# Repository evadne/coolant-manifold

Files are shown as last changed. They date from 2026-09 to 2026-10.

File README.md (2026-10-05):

# Rack coolant manifold and Supernova mount

A ten-pair coolant manifold and a radiator mounting plate for 19-inch open racks. The manifold routes parallel coolant flow through two long galleries in a single machined POM body. A flat stainless faceplate mounts it to the rack; fittings seal directly against raised POM bosses. A separate 10U plate mounts an Alphacool Supernova radiator and four Noctua NF-A20 fans.

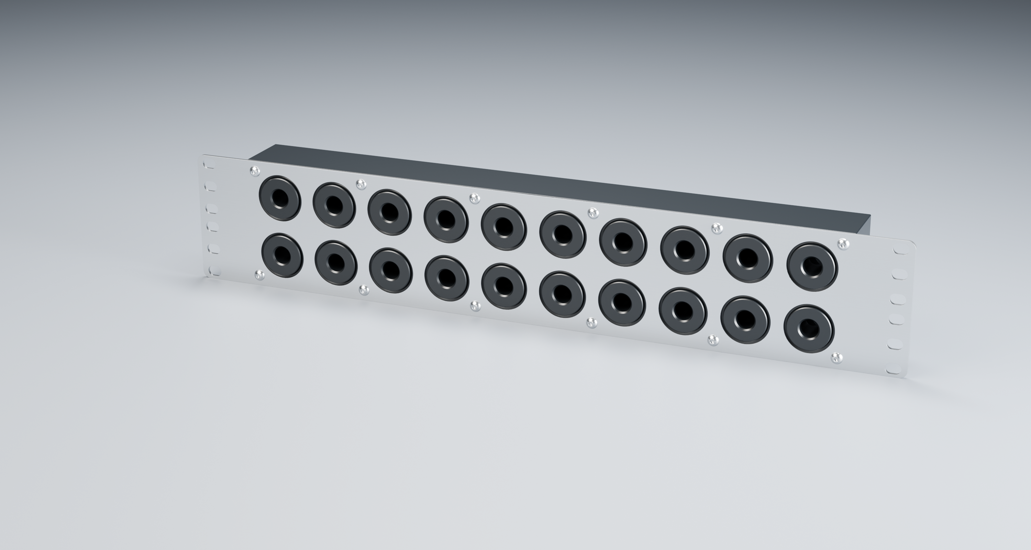
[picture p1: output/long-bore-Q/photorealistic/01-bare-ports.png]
Angled studio render of the assembled manifold with bare ports


*Current Q manifold assembly. Rendered materials are illustrative; the steel fabrication specification is raw sheet finish.*

**To manufacture the same three parts, start with [Order these parts from JLC](docs/order-from-jlc.md).** It lists the exact ZIPs and supplier settings. No CAD software or regeneration is needed to use the existing fabrication pack.

## Canonical fabrication files

Current set: **Q-M04 POM body + Q-M03 faceplate + R7-M01 radiator plate**. These are the revisions used for the delivered first articles. Geometry revisions Q/R7 and manufacturing revisions Q-M04/Q-M03/R7-M01 are distinct; an older Q-M01 body is not the current Q-M04 body.

| Part | Main dimensions in mm | Download for manufacture | Technical drawing |
|---|---|---|---|
| Q-M04 manifold body | 410 × 87 × 40 slab; 3 mm bosses | [Body ZIP](output/submission/current-three-parts/RM10-Q-M04-BODY.zip) | [Body PDF](output/pdf/RM10-Q-M04-BODY.pdf) |
| Q-M03 manifold faceplate | 482.6 × 87 × 2; 2U allocation | [Faceplate ZIP](output/submission/current-three-parts/RM10-Q-M03-FACEPLATE.zip) | [Faceplate PDF](output/pdf/RM10-Q-M03-FACEPLATE.pdf) |
| R7-M01 radiator plate | 482.6 × 444.5 × 2; 10U | [Radiator ZIP](output/submission/current-three-parts/SN1260-R7-M01-PLATE.zip) | [Radiator PDF](output/pdf/SN1260-R7-M01-PLATE.pdf) |

Each ZIP contains one part's STEP and fabrication PDF; steel ZIPs also contain a DXF. **STEP holes are tapping pilots: the accompanying PDF defines the finished G1/4 and M4 threads.** Assembly models, STL meshes and renders are not substitutes for the fabrication bundles.

For tools and AI readers, [cad/current-release.json](cad/current-release.json) lists the canonical revisions, paths and SHA-256 hashes. [The output guide](output/README.md) explains historical and shared dependencies. Earlier versions remain in their original locations.

## What the manifold provides

- Twenty front G1/4 female ports: ten pairs at 40 × 40 mm centres. Four side and four rear ports provide alternative infrastructure connections.
- Two continuous common galleries, with no internal grouping. Feeding from the sides or rear leaves all ten front pairs available for loads.
- One unfilled black POM-C or POM-H body. There is no sealed cover joint; fitted plugs and couplings provide their own face seals.
- Twenty raised bosses with chamfered lips and rounded roots, projecting nominally 1 mm beyond the 2 mm steel plate.
- Twelve plain M4 faceplate fixing holes and optional rack slots. Assembly uses M4×10 button-head screws; no countersinks.

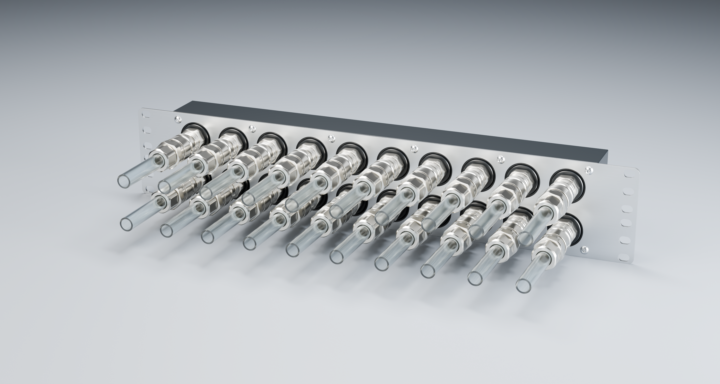
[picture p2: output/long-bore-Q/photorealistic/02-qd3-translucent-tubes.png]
Current manifold with Koolance QD3 pairs and translucent tubing


*Studio presentation uses official, unscaled Koolance QD3-MTG4 and QD3-FT10X13 reference models. Coupled registration is described in the [fitting notes](docs/koolance-qd3-studio-integration.md).*

## Hardware received

The manifold and faceplate have been manufactured. On 5 October 2026, the operator verified their dimensions, the POM M4 holes and G1/4 ports, smooth QD3 engagement and mounting without perceptible plate flex. The radiator plate is delivered but operator-unverified, pending a spare Supernova. No leak-test result has yet been reported.

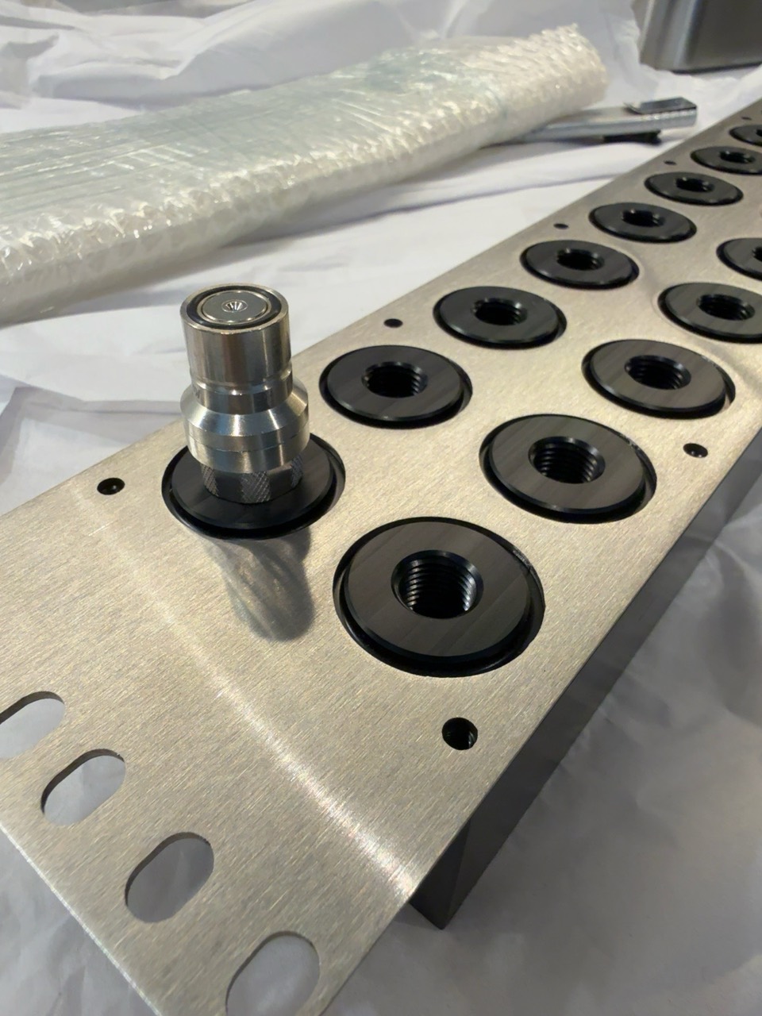
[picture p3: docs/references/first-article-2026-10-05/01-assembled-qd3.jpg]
Received manifold and faceplate with one fitted QD3


*Operator photograph of the first article, during fit checking.*

The first parts were made by **JLCCNC**. Observations about POM holding marks and slight steel-edge sharpness concern that delivered batch; they are documented in the [JLCCNC first-article report](docs/jlc-first-article.md), alongside the accepted fit and remaining finish question. They are not a general judgement of raw stainless steel or other manufacturers.

## Radiator plate and rack context

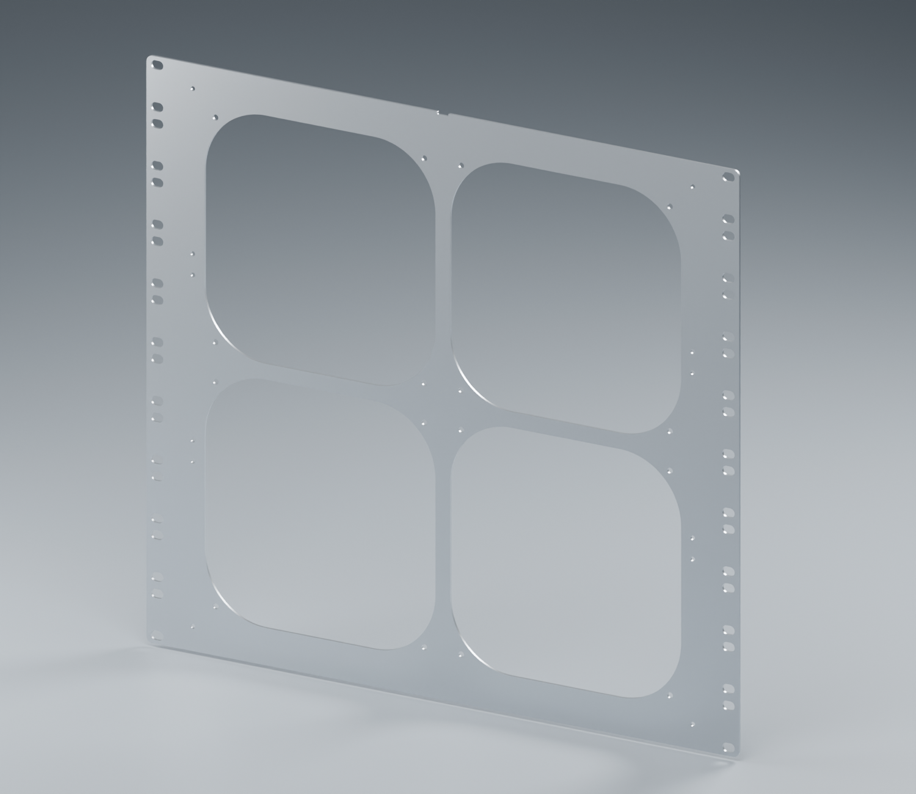
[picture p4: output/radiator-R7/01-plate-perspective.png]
Angled render of the R7 radiator plate


The flat plate has four fan apertures, plain fan fixing holes for screws and nuts, radiator-frame fixing holes, optional rack slots and a rounded cable notch. The illustrated 25U layout places the radiator below the host, the manifold above it and eight water-cooled GPUs higher in the rack. [Assembly guidance](docs/radiator-rack-plate.md) and the [rack scene](docs/context-25U.md) explain the arrangement.

These are prototype designs with physical manifold fit verification, not qualified pressure, transport or long-term creep ratings. Side-elbow clearance to rack hardware remains a separate actual-hardware check. Detailed assumptions and limits are in [manufacturing status](docs/manufacturing.md) and the linked engineering studies.

## Explore or reproduce the project

| Goal | Start here |
|---|---|
| Order the same parts | [JLC repeat-order guide](docs/order-from-jlc.md) |
| Understand dimensions and materials | [Three-part recap](docs/three-part-recap.md) |
| Assemble the manifold | [Assembly guide](docs/assembly-Q.md) |
| Find engineering evidence and history | [Documentation index](docs/README.md) |
| Rebuild CAD, PDFs or Blender scenes | [Rebuild guide](docs/rebuild.md) |
| Read the project retrospective | [Astra's commentary](docs/astra-commentary.md) |
| Make and order a new revision | [Contributor workflow](docs/new-revision.md) |
| Set up macOS authoring tools | [Environment setup](docs/rebuild.md#environment) |
| Contribute changes | [Working rules](AGENTS.md) |

The repository retains substantial CAD, Blender and analysis history. The [publication review](docs/publication-review.md) records repository size, retained supplier records, third-party assets and portability limits. Original project material is licensed under **[CERN-OHL-W-2.0](LICENSE)**; see [licensing and provenance](LICENSING.md) for scope and third-party notices. No blanket reuse grant is implied for manufacturer reference models.

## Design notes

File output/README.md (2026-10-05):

# Output directory guide

Current custom parts: Q-M04 manifold body, Q-M03 faceplate and R7/R7-M01 radiator; both steel plates have four R5 outside corners and ±0.10 cut tolerances. These are the delivered first-article revisions. Start with [the repeat-order guide](../docs/order-from-jlc.md) or [machine-readable selection](../cad/current-release.json).

| Location | Purpose |
|---|---|
| `submission/releases/<name>/` | Independently reviewed quotation packs from `scripts/release.py`; these do not automatically change the canonical delivered selection |
| `submission/current-three-parts/` | Current three-part ZIP index and final consistency manifest |
| `submission/Q-M04/`, `submission/Q-M03/` | Body/faceplate supplier STEP/PDF ZIPs; DXF for steel; checks and remarks |
| `submission/R7-M01/` | Radiator STEP/PDF/DXF ZIP; checks and remarks |
| `manufacturing/Q-M04/`, `manufacturing/Q-M03/`, `manufacturing/R7-M01/` | Derived single-part solids and verified feature schedules |
| `pdf/RM10-Q-M04-BODY.pdf`, `pdf/RM10-Q-M03-FACEPLATE.pdf`, `pdf/SN1260-R7-M01-PLATE.pdf` | Current technical fabrication drawings |
| `assembly/Q/` | Separate reference assembly and selected M4×10 screw; not supplier part uploads |
| `long-bore-Q/cad/` | Original Q-M01 body and baseline geometry/checks; original faceplate/assembly retained as source history. Current plate is manufacturing/Q-M03; current assembly is assembly/Q |
| `long-bore-Q/product-views/` | Current twelve review angles and unmarked/transparent Blender scenes |
| `long-bore-Q/photorealistic/` | Four refreshed studio images, bare/connected Blender scenes |
| `long-bore-P/koolance-fit/` | Shared retained official fitting meshes and provenance |
| `radiator-R7/` | Current radiator CAD, checks and seven refreshed plate/populated assembly/notch/R5 views |
| `context-25U/` | Current Q/R7 StarTech composite, nine views and fit/tubing checks |
| `analysis/Q-retention.json`, `analysis/Q-torque.json` | Explicit preliminary assumptions and numerical sensitivity; not qualified ratings |

Earlier P/O, Q-M01 and R6 manufacturer/review files are historical; do not submit them as the current Q-M04/Q-M03/R7-M01 set. Older `long-bore-*`, `radiator-R1` throughR6, generic24U scenes and unversioned G outputs retain their original history. The R4 FEA remains baseline evidence, not a new R7/Q solver result. [Project guide](../README.md) · [manufacturing](../docs/manufacturing.md) · [assembly](../docs/assembly-Q.md).

## Authority and dependencies

Only the three ZIPs selected by `cad/current-release.json` are canonical fabrication uploads. The current index contains byte-identical copies of the revision-specific archives. PDFs plus STEP/DXF define fabrication; STL and Blender files are display/assembly aids. The original files are retained in place rather than renamed, because historical scripts and current reference scenes still depend on some of them.

A directory labelled `long-bore-Q` is not enough to choose a supplier file: its `cad/` subdirectory retains baseline Q-M01 solids, while current presentation scripts load the finished Q-M04/Q-M03 parts explicitly. `long-bore-P/koolance-fit/` is a shared current reference dependency despite its older revision name. The [revision register](../docs/iterations.md) describes the progression.

No Git LFS migration or historical asset removal has been performed. Large scenes and solver outputs are intentionally retained. Use [the publication review](../docs/publication-review.md) for size/provenance decisions, not a renderer's defaults.

Historical verification records can contain status text from the release date (for example “held” or “submitted”). Preserve that dated meaning when maintaining metadata; field names, source paths and checksums use the current format, with earlier records retained in Git. The canonical manifest selects the parts; [manufacturing status](../docs/manufacturing.md) describes their current physical disposition.

Renderer inputs are retained beside the owning revision: `meshes/` contains tessellations and `render-scene.json` contains placement parameters. The unversioned G inputs live directly under `output/`; its alternative mounting uses `backplate/`. O-M02 presentation meshes live under `manufacturing/O-M02/meshes/`. Q's gallery meshes are diagnostic void volumes; current part surfaces still come from Q-M04/Q-M03.

Structural studies retain compressed `.inp.gz` solver decks, `.dat.gz` results and `.json.gz` node/load metadata together under `radiator-FEA/`, `radiator-expanded-load/`, `radiator-R2/analysis/` and `radiator-R4/analysis/`. Review scripts read these directly. `context-24U/history/`, `context-25U/history/` and `analysis/historical-body-depth-assessment.json` hold earlier exploratory evidence, not current acceptance results.

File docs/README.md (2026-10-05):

# Documentation guide

For another order, use [Order the current parts from JLC](order-from-jlc.md). For current file selection, use [the canonical manifest](../cad/current-release.json) and [fabrication downloads](../output/submission/current-three-parts/README.md). Historical documents retain the context of their original dates; they do not select today's files.

| Subject | Documents |
|---|---|
| Design and interfaces | [Three-part recap](three-part-recap.md), [design](design.md), [Q rear ports](revision-Q-rear-ports.md) |
| Delivered parts and supplier experience | [Manufacturing status](manufacturing.md), [JLCCNC first article](jlc-first-article.md), [order chronology](jlc-order-2026-09-16.md) |
| Manufacture again | [JLC guide](order-from-jlc.md), [body revision](jlc-submission-Q-M04.md), [faceplate revision](jlc-submission-Q-M03.md), [radiator revision](jlc-submission-R7-M01.md) |
| Assembly | [Manifold](assembly-Q.md), [radiator](radiator-rack-plate.md), [fan splitter](radiator-x-splitter-fit.md) |
| Engineering evidence | [Machining route](Q-M04-machining-route.md), [M4 sizing](Q-retention-sizing.md), [torque/creep](Q-torque-and-creep.md), [radiator loads](radiator-load-assessment.md) |
| Coolant assumptions | [POM compatibility](pom-coolant-assessment.md), [Blitz overrun targets](blitz-overrun-qualification.md), [pump pressure](d5-pressure.md) |
| Product presentation | [Views](product-views.md), [Koolance references](koolance-qd3-studio-integration.md), [25U rack](context-25U.md) |
| Rack model details | [PVC equilibrium](pvc-routing-physics.md), [GPU geometry](gpu-5090fe-context.md) |
| New designs | [Create, check and package a revision](new-revision.md) |
| Reproduction | [Rebuild guide](rebuild.md), [output map](../output/README.md) |
| History and reflection | [Revision register](iterations.md), [archive](archive/README.md), [Astra's commentary](astra-commentary.md) |
| Publication | [Review](publication-review.md), [licensing/provenance](../LICENSING.md) |

`AGENTS.md` contains working rules. Rationale belongs in the engineering documents; dated events belong in the order/revision records; supplier-specific findings belong in the JLCCNC report. Numerical and simulated evidence is not silently upgraded to first-article test evidence.

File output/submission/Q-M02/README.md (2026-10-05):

# Q-M02 manifold faceplate submission guide

Issued 16 September 2026. **RM10-Q-M02-FACEPLATE** replaces the Q-M01 faceplate specification only. The accepted Q geometry is unchanged; the POM body remains **RM10-Q-M01-BODY**, with its existing threads, positions and finishes.

Use `output/submission/Q-M02/RM10-Q-M02-FACEPLATE.zip` as one sheet-metal part. It contains matching-name STEP, DXF and two-sheet A3 PDF. The STEP/DXF are byte-identical to the submitted Q-M01 geometry, renamed for this manufacturing issue.

- Material: 304 / EN 1.4301 stainless, 482.6 ×87 ×2 mm, raw sheet finish on both broad faces; no brushing, polishing, coating or markings.
- All non-reference cut dimensions, including hole diameters, slot sizes, profiles and all X/Z coordinates: **±0.10 mm**. Thickness: 2.00 ±0.10 mm.
- W01–W20: Ø32.00 ±0.10 mm windows. H01–H12: Ø4.50 ±0.10 mm plain through holes. R01–R12: 10.00 ±0.10 ×7.00 ±0.10 mm slots; end radius half finished width.
- Free-state flatness: **0.30 mm maximum**, unchanged and separate from dimensional tolerances.
- Standard grinding and deburring on both faces; no specified chamfer or face-edge round size. Complete burr removal is not guaranteed, consistent with the operator-accepted JLC faceplate limitation.
- No tapped holes, countersinks, bends or welds. Manufacturing instructions only; assembly remains in the separate Q assembly guide.

The twelve hole positions and all nominal diameters remain unchanged. The earlier proposed Ø4.5 minimum-hole condition is not retained: the new specification allows Ø4.40–4.60 mm. The [fit assessment](../../../docs/Q-faceplate-as-drawn-capability.md) and [operator acceptance](jlc-feedback-2026-09-16.md#operator-acceptance) are engineering records outside the fabrication ZIP.

**Held for later submission if a repeat order is needed**, by operator decision on 16 September 2026. This package records the accepted dimensional tolerances. Do not replace the current order’s files. The existing order **SMS2609163000694-6347288A** proceeds under the operator’s emailed acceptance; it is a historical reference, not an order for this new issue. No upload of this issue has occurred. Original Q-M01 submitted archives remain intact; see [quotation history](../../../docs/jlc-quotation-2026-09-15.md).

Rebuild: `python3 scripts/prepare_Q_faceplate_manufacturing_revision.py`, then `python3 scripts/draw_Q_production.py --faceplate-manufacturing-revision Q-M02 --faceplate-only`. Render and inspect both sheets, then run `python3 scripts/package_Q_faceplate_manufacturing_revision.py`. Use a Python runtime with ReportLab/pypdf for the final two commands.

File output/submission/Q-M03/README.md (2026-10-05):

# Q-M03 manifold faceplate submission guide

Issued 16 September 2026. **RM10-Q-M03-FACEPLATE** supersedes Q-M02 with four R5 external outline corners; every opening and fixing position is retained; the current companion POM body is **RM10-Q-M04-BODY**, which adds C0.5 slab-edge chamfers while retaining all threads and mating positions.

Use `output/submission/Q-M03/RM10-Q-M03-FACEPLATE.zip` as one sheet-metal part. It contains matching-name STEP, DXF and two-sheet A3 PDF. The STEP/DXF model four R5.00 ±0.10 mm external outline corners. Compared with the submitted square-corner faceplate, only 42.920 mm³ is removed; no material is added. Nominal mass is 0.394607 kg. The minimum opening-to-outer-profile clearance remains 1.90 mm.

- Material: 304 / EN 1.4301 stainless, 482.6 ×87 ×2 mm, raw sheet finish on both broad faces; no brushing, polishing, coating or markings.
- All non-reference cut dimensions, including hole diameters, slot sizes, profiles and all X/Z coordinates: **±0.10 mm**. Thickness: 2.00 ±0.10 mm.
- W01–W20: Ø32.00 ±0.10 mm windows. H01–H12: Ø4.50 ±0.10 mm plain through holes. R01–R12: 10.00 ±0.10 ×7.00 ±0.10 mm slots; end radius half finished width.
- Free-state flatness: **0.30 mm maximum**, unchanged and separate from dimensional tolerances.
- Standard grinding and deburring on both faces; no specified chamfer or face-edge round size. Complete burr removal is not guaranteed, consistent with the operator-accepted JLC faceplate limitation.
- No tapped holes, countersinks, bends or welds. Manufacturing instructions only; assembly remains in the separate Q assembly guide.

The twelve hole positions and all nominal diameters remain unchanged. The earlier proposed Ø4.5 minimum-hole condition is not retained: the new specification allows Ø4.40–4.60 mm. The [fit assessment](../../../docs/Q-faceplate-as-drawn-capability.md) and [operator acceptance](../../../docs/jlc-feedback-2026-09-16.md#operator-acceptance) are engineering records outside the fabrication ZIP.

**Held for later submission if a repeat order is needed**, by operator decision on 16 September 2026. This package records the accepted dimensional tolerances. Do not replace the current order’s files. The existing order **SMS2609163000694-6347288A** proceeds under the operator’s emailed acceptance; it is a historical reference, not an order for this new issue. No upload of this issue has occurred. Original Q-M01 submitted archives remain intact; see [quotation history](../../../docs/jlc-quotation-2026-09-15.md).

Rebuild: `.venv/bin/python scripts/prepare_Q_faceplate_manufacturing_revision.py --manufacturing-revision Q-M03`, then `python3 scripts/draw_Q_production.py --faceplate-manufacturing-revision Q-M03 --faceplate-only`. Render and inspect both sheets, then run `python3 scripts/package_Q_faceplate_manufacturing_revision.py --manufacturing-revision Q-M03`. Use a Python runtime with ReportLab/pypdf for the final two commands.

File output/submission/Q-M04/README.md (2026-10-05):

# Q-M04 POM body fabrication issue

Issued 16 September 2026. Part **RM10-Q-M04-BODY** supersedes Q-M01 for the held repeat-order pack. Its twelve main-block outside edges have **C0.50 ±0.10 mm ×45° ±1° chamfers**, modelled in STEP. The eight triangular corner flats follow the model. All other geometry and manufacturing requirements are retained.

Use `output/submission/Q-M04/RM10-Q-M04-BODY.zip`: one single-part STEP and matching three-sheet A3 PDF. Thread cylinders represent tapping pilots; the PDF specifies finished threads. This is a CNC part, not sheet metal.

- Black unfilled declared POM-C or POM-H machining stock; 410 ×87 ×40 mm main slab and twenty Ø28 ×3 mm front bosses, 43 mm overall depth.
- Twenty front, four end and four rear G1/4 female ports; 8 mm minimum full thread after entry; ISO 228-1, gauged to ISO 228-2. Two Ø11.8 continuous galleries. Follow the drawing for all pilot depths and drill points.
- Twelve M4 ×0.7-6H blind retention holes; 10 mm minimum full thread after entry, Ø3.3 ×13 mm full-diameter pilots plus 118° points. Entry Ø4.4 ×90° included, 0.55 mm nominal depth. Gauge to ISO 1502.
- Retain R1 boss roots, C0.5 ×45° boss lips and all G1/4 entry chamfers. The new perimeter chamfer applies only to the twelve outer slab edges.
- Preserve the specified front, rear and end sealing lands and front mounting plane. Ra ≤1.6 µm and local flatness ≤0.05 mm on seal lands; other finishes, datum flatness and coordinates per PDF.
- Other unspecified external edges: break 0.20 mm maximum. No internal bore/cross-hole deburring operation; clean and flush loose chips. Deliver clean, dry and unmarked.

STEP comparison confirms only the slab-perimeter chamfers remove material: 267.833 mm³ total. Every curved face, hole and boss feature is unchanged, and the specified sealing lands and M4 bearing areas are outside the removed volume. Finished solid is valid; no material is added. The drawing includes an enlarged edge detail and explicit perimeter call-out.

Rebuild using `.venv/bin/python scripts/prepare_Q_body_manufacturing_revision.py`, then `python3 scripts/draw_Q_production.py --body-manufacturing-revision Q-M04 --body-only` with ReportLab. Render and inspect all three PDF sheets, then run `python3 scripts/package_Q_body_manufacturing_revision.py` with pypdf. The body preparation also refreshes the separate reference assembly with the current Q-M03 faceplate; run it after faceplate preparation.

**Held for a future repeat order.** Do not replace the current JLC order files; original Q-M01 submitted files remain intact. This issue has not been submitted. Assembly hardware, torque and installation instructions remain outside this fabrication ZIP.

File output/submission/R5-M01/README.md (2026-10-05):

# R5-M01 radiator plate production pack

Issued 15 September 2026. Part **SN1260-R5-M01-PLATE** adds the requested rounded cable notch to the operator-approved, non-tapped R4 radiator plate. It supersedes R4-M01 for fabrication; the R4 pack is preserved. The manifold package remains separate.

## Upload files

Use `output/submission/R5-M01/SN1260-R5-M01-PLATE.zip` as one part. It contains identically named STEP, DXF and three-sheet A3 PDF files. The STEP is a single finished nominal solid; the DXF is the 1:1 millimetre cut profile. The drawing defines tolerances, edge breaks and finish. Report conflicts before cutting; do not silently substitute nominal model sizes for drawing limits.

Suggested route: JLC's sheet-metal service, stainless steel 304, 2 mm, brushed finish. No bends, tapping, countersinking, welding, inserted hardware or supplier assembly. Round holes may be laser-cut where the specified finished dimensions are met, otherwise drilled/finished. This avoids prescribing an unnecessary separate drilling operation.

JLC's [sheet-metal fabrication guidelines](https://jlccnc.com/help/article/sheet-metal-fabrication-guidelines) require STEP/STP, accept PDF/DXF supplementary drawings and permit ZIP uploads containing STEP; matching file names are recommended. Their listed minima are 1 mm hole spacing and cut diameter at least 1 mm and half the sheet thickness. Published general/cutting/hole tolerances do not automatically establish compliance with this drawing's unilateral hole limits, cable-notch edge finish or free-state flatness. Checked 15 September 2026.

JLC lists 2 mm 304 sheet and an 800 mm maximum length in its [supported sheet-metal materials](https://jlccnc.com/help/article/materials-supported-in-sheet-metal-fabrication). This part's maximum extent is 482.6 mm. These catalogue checks support requesting a quotation, not a confirmed supplier acceptance.

## Drawing coverage

| Group | Quantity | Finished feature |
|---|---:|---|
| A01–A16 | 16 | Ø4.50 +0.15/0 through; M4 fan screws with separate nuts |
| B01–B12 | 12 | Ø3.60 +0.15/0 through; M3 screws into the radiator frame |
| C01–C40 | 40 | Horizontal 10.00 ±0.15 × 7.00 +0.15/0 through slots |
| D01–D04 | 4 | 188.00 ±0.15 square, R50.00 ±0.15 through apertures |
| E01 | 1 | Top-centre open cable notch: 10.00 ±0.15 mouth × 5.00 ±0.15 depth, R1 mouth and R2 bottom transitions |

Sheet 1 identifies every feature and specifies the profile, material, finish and edge treatment. Sheet 2 schedules the fixing and aperture coordinates and details the slot and sheet thickness. Sheet 3 details E01, centred at X0 ±0.10 on the top edge. Its 10 mm mouth includes the two R1 entry transitions; the parallel throat is 8 mm and the bottom flat is 4 mm. All four corners are tangent arcs. No sloped ramp is needed. All holes are normal to the broad faces; there is no countersink angle or tapped thread in this plate. M3 threads belong to the bought-in radiator only.

Overall dimensions are 482.60 ±0.15 × 444.50 +0/−0.15 × 2.00 ±0.10 mm. The height retains the accepted nominal 10U geometry. Hole/slot centres are ±0.10 mm from the defined width-centre/bottom-edge origin. Whole-plate free-state flatness is 0.50 mm maximum. Supplier acceptance of these requirements is required before fabrication; do not assume portal defaults override them.

## Manufacturing and inspection review

The smallest round hole is 3.6 mm. Nominal rack-slot end margins are 2.85 mm vertically and 3.75 mm laterally; the nearest adjacent slot gap is 5.70 mm. Central aperture webs are 12 mm. None of these dimensions require a sub-millimetre cut ligament. The thin, broad plate should be inspected without fixture forces masking distortion.

Deburr both faces: fan holes have only a 0.10 mm maximum edge break; other cut edges have a 0.20–0.30 mm break, except E01. At E01, continuously round the cable-contact edges R0.30–0.50 on both faces and blend into the adjacent top edge. Remove burrs, sharp lips and rough cut striations. These small face rounds are specified separately from the R1/R2 cut-profile radii. These finishing details are drawing requirements, not extra machined STEP chamfers. Specify uniform satin brushing with no product markings or applied coating. Do not infer electrical isolation from the finish.

CAD verification confirms one valid solid, 72 openings, all 68 fixing positions and matching circular DXF coordinates. The production STEP is byte-identical to the R5 source. A solid comparison against R4 verifies that the only removed material is the 10 × 5 mm notch envelope (77.425 mm³); there is no added material. Nominal net mass is 1.247 kg using 7,900 kg/m³; finishing is not deducted. The notch removes about 0.612 g at the top centre and leaves the mount patterns and central web intact. R4 structural analysis remains historical baseline evidence; no new R5 FEA or assembly load rating is claimed.

First article: inspect thickness, overall dimensions, all fixing positions, finished hole/slot sizes, aperture profiles, edge treatment and free-state flatness. Trial-fit the actual radiator, fans and intended cable route before further production; the notch is for the cable rather than a specified connector envelope. Check that the adjoining radiator surface does not pinch the cable. Also, M3 engagement and real hardware clearances remain assembly checks outside this plate-only supplier order.

## Assembly retained from R4

1. Fit fans to the plate. M4 ×40 button heads and washers are on the radiator/core side; nuts and washers are outside the fan faces.
2. Fix the populated plate to the radiator through the twelve M3 clearance holes.
3. Mount the assembly to the rack using the chosen optional rack positions.

Use the existing R4 assembly notes for hardware details. If using the X-Splitter, retain/insulate it with suitable nonconductive double-sided tape. No additional holes are required.

## Reproduction and records

Build geometry first with `scripts/build_radiator_plate.py --revision R5`. Run `scripts/prepare_radiator_production.py` with the CAD environment, with `--manufacturing-revision R5-M01`, then `scripts/draw_radiator_production.py --manufacturing-revision R5-M01` with ReportLab. Render and visually inspect all three PDF pages before running `scripts/package_radiator_production.py --manufacturing-revision R5-M01` with pypdf. The package script checks drawing coverage and ZIP integrity and records SHA-256 hashes. Geometry/source data stay in `output/manufacturing/R5-M01/`; the upload bundle and supplier remarks are in `output/submission/R5-M01/`.

This issue prepares the files only. No supplier upload, quotation acceptance or order has been made.

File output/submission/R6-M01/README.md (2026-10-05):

# R6-M01 radiator plate production pack

Issued 15 September 2026. R6 operator-approved on 15 September 2026. Part **SN1260-R6-M01-PLATE** adds the requested shallow 10 × 2 mm rounded cable notch to the operator-approved, non-tapped R4 radiator plate. It supersedes R5-M01 for fabrication; the earlier R4 and 10 × 5 mm R5 packs are preserved. The manifold package remains separate.

## Upload files

Use `output/submission/R6-M01/SN1260-R6-M01-PLATE.zip` as one part. It contains identically named STEP, DXF and three-sheet A3 PDF files. The STEP is a single finished nominal solid; the DXF is the 1:1 millimetre cut profile. The drawing defines tolerances, edge breaks and finish. Report conflicts before cutting; do not silently substitute nominal model sizes for drawing limits.

Suggested route: JLC's sheet-metal service, stainless steel 304, 2 mm, brushed finish. No bends, tapping, countersinking, welding, inserted hardware or supplier assembly. Round holes may be laser-cut where the specified finished dimensions are met, otherwise drilled/finished. This avoids prescribing an unnecessary separate drilling operation.

JLC's [sheet-metal fabrication guidelines](https://jlccnc.com/help/article/sheet-metal-fabrication-guidelines) require STEP/STP, accept PDF/DXF supplementary drawings and permit ZIP uploads containing STEP; matching file names are recommended. Their listed minima are 1 mm hole spacing and cut diameter at least 1 mm and half the sheet thickness. Published general/cutting/hole tolerances do not automatically establish compliance with this drawing's unilateral hole limits, cable-notch edge finish or free-state flatness. Checked 15 September 2026.

JLC lists 2 mm 304 sheet and an 800 mm maximum length in its [supported sheet-metal materials](https://jlccnc.com/help/article/materials-supported-in-sheet-metal-fabrication). This part's maximum extent is 482.6 mm. These catalogue checks support requesting a quotation, not a confirmed supplier acceptance.

## Drawing coverage

| Group | Quantity | Finished feature |
|---|---:|---|
| A01–A16 | 16 | Ø4.50 +0.15/0 through; M4 fan screws with separate nuts |
| B01–B12 | 12 | Ø3.60 +0.15/0 through; M3 screws into the radiator frame |
| C01–C40 | 40 | Horizontal 10.00 ±0.15 × 7.00 +0.15/0 through slots |
| D01–D04 | 4 | 188.00 ±0.15 square, R50.00 ±0.15 through apertures |
| E01 | 1 | Top-centre open cable notch: 10.00 ±0.15 mouth × 2.00 ±0.15 depth, R0.5 mouth and bottom transitions |

Sheet 1 identifies every feature and specifies the profile, material, finish and edge treatment. Sheet 2 schedules the fixing and aperture coordinates and details the slot and sheet thickness. Sheet 3 details E01, centred at X0 ±0.10 on the top edge. Its 10 mm mouth includes the two R0.5 entry transitions; the parallel throat is 9 mm and the bottom flat is 8 mm. All four corners are tangent arcs. No sloped ramp is needed. All holes are normal to the broad faces; there is no countersink angle or tapped thread in this plate. M3 threads belong to the bought-in radiator only.

Overall dimensions are 482.60 ±0.15 × 444.50 +0/−0.15 × 2.00 ±0.10 mm. The height retains the accepted nominal 10U geometry. Hole/slot centres are ±0.10 mm from the defined width-centre/bottom-edge origin. Whole-plate free-state flatness is 0.50 mm maximum. Supplier acceptance of these requirements is required before fabrication; do not assume portal defaults override them.

## Manufacturing and inspection review

The smallest round hole is 3.6 mm. Nominal rack-slot end margins are 2.85 mm vertically and 3.75 mm laterally; the nearest adjacent slot gap is 5.70 mm. Central aperture webs are 12 mm. None of these dimensions require a sub-millimetre cut ligament. The thin, broad plate should be inspected without fixture forces masking distortion.

Deburr both faces: fan holes have only a 0.10 mm maximum edge break; other cut edges have a 0.20–0.30 mm break, except E01. At E01, continuously round the cable-contact edges R0.30–0.50 on both faces and blend into the adjacent top edge. Remove burrs, sharp lips and rough cut striations. These small face rounds are specified separately from the R0.5 cut-profile radii. These finishing details are drawing requirements, not extra machined STEP chamfers. Specify uniform satin brushing with no product markings or applied coating. Do not infer electrical isolation from the finish.

CAD verification confirms one valid solid, 72 openings, all 68 fixing positions and matching circular DXF coordinates. The production STEP is byte-identical to the R6 source. A solid comparison against R4 verifies that the only removed material is the 10 × 2 mm notch envelope (36.000 mm³); there is no added material. Nominal net mass is 1.247 kg using 7,900 kg/m³; finishing is not deducted. The notch removes about 0.284 g at the top centre and leaves the mount patterns and central web intact. R4 structural analysis remains historical baseline evidence; no new R6 FEA or assembly load rating is claimed.

First article: inspect thickness, overall dimensions, all fixing positions, finished hole/slot sizes, aperture profiles, edge treatment and free-state flatness. Trial-fit the actual radiator, fans and intended cable route before further production; the notch is for the cable rather than a specified connector envelope. Check that the adjoining radiator surface does not pinch the cable. Also, M3 engagement and real hardware clearances remain assembly checks outside this plate-only supplier order.

## Assembly retained from R4

1. Fit fans to the plate. M4 ×40 button heads and washers are on the radiator/core side; nuts and washers are outside the fan faces.
2. Fix the populated plate to the radiator through the twelve M3 clearance holes.
3. Mount the assembly to the rack using the chosen optional rack positions.

Use the current R6 assembly notes (`docs/radiator-rack-plate.md` in the project) for hardware details. If using the X-Splitter, retain/insulate it with suitable nonconductive double-sided tape. No additional holes are required.

## Reproduction and records

The shallow notch supersedes the previous 5 mm depth; its floor is Y442.500.

Build geometry first with `scripts/build_radiator_plate.py --revision R6`. Run `scripts/prepare_radiator_production.py` with the CAD environment, with `--manufacturing-revision R6-M01`, then `scripts/draw_radiator_production.py --manufacturing-revision R6-M01` with ReportLab. Render and visually inspect all three PDF pages before running `scripts/package_radiator_production.py --manufacturing-revision R6-M01` with pypdf. The package script checks drawing coverage and ZIP integrity and records SHA-256 hashes. Geometry/source data stay in `output/manufacturing/R6-M01/`; the upload bundle and supplier remarks are in `output/submission/R6-M01/`.

This issue prepares the files only. No supplier upload, quotation acceptance or order has been made.

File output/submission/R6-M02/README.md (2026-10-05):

# R6-M02 radiator plate production pack

Issued 15 September 2026. R6 operator-approved on 15 September 2026. Part **SN1260-R6-M02-PLATE** adds the requested shallow 10 × 2 mm rounded cable notch to the operator-approved, non-tapped R4 radiator plate. R6-M02 supersedes R6-M01 for finish specification only; the approved R6 geometry is unchanged. The manifold package remains separate.

## Upload files

Use `output/submission/R6-M02/SN1260-R6-M02-PLATE.zip` as one part. It contains identically named STEP, DXF and three-sheet A3 PDF files. The STEP is a single finished nominal solid; the DXF is the 1:1 millimetre cut profile. The drawing defines tolerances, edge breaks and finish. Report conflicts before cutting; do not silently substitute nominal model sizes for drawing limits.

Suggested route: JLC's sheet-metal service, stainless steel 304, 2 mm, raw sheet finish, no brushing or polishing. Flat plate with plain through holes; no tapping or countersinks. Round holes may be laser-cut where the specified finished dimensions are met, otherwise drilled/finished. This avoids prescribing an unnecessary separate drilling operation.

JLC's [sheet-metal fabrication guidelines](https://jlccnc.com/help/article/sheet-metal-fabrication-guidelines) require STEP/STP, accept PDF/DXF supplementary drawings and permit ZIP uploads containing STEP; matching file names are recommended. Their listed minima are 1 mm hole spacing and cut diameter at least 1 mm and half the sheet thickness. Published general/cutting/hole tolerances do not automatically establish compliance with this drawing's unilateral hole limits, cable-notch edge finish or free-state flatness. Checked 15 September 2026.

JLC lists 2 mm 304 sheet and an 800 mm maximum length in its [supported sheet-metal materials](https://jlccnc.com/help/article/materials-supported-in-sheet-metal-fabrication). This part's maximum extent is 482.6 mm. These catalogue checks support requesting a quotation, not a confirmed supplier acceptance.

## Drawing coverage

| Group | Quantity | Finished feature |
|---|---:|---|
| A01–A16 | 16 | Ø4.50 +0.15/0 through; plain clearance holes |
| B01–B12 | 12 | Ø3.60 +0.15/0 through; plain clearance holes |
| C01–C40 | 40 | Horizontal 10.00 ±0.15 × 7.00 +0.15/0 through slots |
| D01–D04 | 4 | 188.00 ±0.15 square, R50.00 ±0.15 through apertures |
| E01 | 1 | Top-centre open cable notch: 10.00 ±0.15 mouth × 2.00 ±0.15 depth, R0.5 mouth and bottom transitions |

Sheet 1 identifies every feature and specifies the profile, material, finish and edge treatment. Sheet 2 schedules the fixing and aperture coordinates and details the slot and sheet thickness. Sheet 3 details E01, centred at X0 ±0.10 on the top edge. Its 10 mm mouth includes the two R0.5 entry transitions; the parallel throat is 9 mm and the bottom flat is 8 mm. All four corners are tangent arcs. No sloped ramp is needed. All holes are normal to the broad faces; there is no countersink angle or tapped thread in this plate.

Overall dimensions are 482.60 ±0.15 × 444.50 +0/−0.15 × 2.00 ±0.10 mm. The height retains the accepted nominal 10U geometry. Hole/slot centres are ±0.10 mm from the defined width-centre/bottom-edge origin. Whole-plate free-state flatness is 0.50 mm maximum. Supplier acceptance of these requirements is required before fabrication; do not assume portal defaults override them.

## Manufacturing and inspection review

The smallest round hole is 3.6 mm. Nominal rack-slot end margins are 2.85 mm vertically and 3.75 mm laterally; the nearest adjacent slot gap is 5.70 mm. Central aperture webs are 12 mm. None of these dimensions require a sub-millimetre cut ligament. The thin, broad plate should be inspected without fixture forces masking distortion.

Deburr both faces: fan holes have only a 0.10 mm maximum edge break; other cut edges have a 0.20–0.30 mm break, except E01. At E01, continuously round the cable-contact edges R0.30–0.50 on both faces and blend into the adjacent top edge. Remove burrs, sharp lips and rough cut striations. These small face rounds are specified separately from the R0.5 cut-profile radii. These finishing details are drawing requirements, not extra machined STEP chamfers. Specify raw stainless sheet finish on BOTH broad faces, with no brushing, polishing, product markings or applied coating.

CAD verification confirms one valid solid, 72 openings, all 68 fixing positions and matching circular DXF coordinates. The production STEP is byte-identical to the R6 source. A solid comparison against R4 verifies that the only removed material is the 10 × 2 mm notch envelope (36.000 mm³); there is no added material. Nominal net mass is 1.247 kg using 7,900 kg/m³; finishing is not deducted. The notch removes about 0.284 g at the top centre and leaves the mount patterns and central web intact.

First article: inspect thickness, overall dimensions, all fixing positions, finished hole/slot sizes, aperture profiles, edge treatment and free-state flatness.

Assembly instructions are maintained separately in [the radiator assembly guide](../../../docs/radiator-rack-plate.md).

## Reproduction and records

The shallow notch supersedes the previous 5 mm depth; its floor is Y442.500.

Build geometry first with `scripts/build_radiator_plate.py --revision R6`. Run `scripts/prepare_radiator_production.py` with the CAD environment, with `--manufacturing-revision R6-M02`, then `scripts/draw_radiator_production.py --manufacturing-revision R6-M02` with ReportLab. Render and visually inspect all three PDF pages before running `scripts/package_radiator_production.py --manufacturing-revision R6-M02` with pypdf. The package script checks drawing coverage and ZIP integrity and records SHA-256 hashes. Geometry/source data stay in `output/manufacturing/R6-M02/`; the upload bundle and supplier remarks are in `output/submission/R6-M02/`.

The generation scripts prepare local files only; the separate quotation status below records the authorised supplier submission. Supplier acceptance and payment remain pending.

R6-M02 supersedes R6-M01. Before quotation, the operator amended both steel parts to raw sheet finish with no brushing or polishing. STEP/DXF geometry remains byte-identical to approved R6. See [current three-part JLC review](../../../docs/jlc-final-review.md).

## Quotation status

[Submitted to JLCCNC for review before payment](../../../docs/jlc-quotation-2026-09-15.md), with raw sheet finish. No payment made.

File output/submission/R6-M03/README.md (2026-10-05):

# R6-M03 radiator plate production pack

Issued 16 September 2026. R6 operator-approved on 15 September 2026. Part **SN1260-R6-M03-PLATE** adds the requested shallow 10 × 2 mm rounded cable notch to the operator-approved, non-tapped R4 radiator plate. R6-M03 supersedes R6-M02 for ±0.10 mm cut-size and coordinate tolerances; the approved R6 geometry is unchanged. The manifold package remains separate.

## Upload files

Use `output/submission/R6-M03/SN1260-R6-M03-PLATE.zip` as one part. It contains identically named STEP, DXF and three-sheet A3 PDF files. The STEP is a single finished nominal solid; the DXF is the 1:1 millimetre cut profile. The drawing defines tolerances, edge breaks and finish. Report conflicts before cutting; do not silently substitute nominal model sizes for drawing limits.

Suggested route: JLC's sheet-metal service, stainless steel 304, 2 mm, raw sheet finish, no brushing or polishing. Flat plate with plain through holes; no tapping or countersinks. Round holes may be laser-cut where the specified finished dimensions are met, otherwise drilled/finished. This avoids prescribing an unnecessary separate drilling operation.

JLC's [sheet-metal fabrication guidelines](https://jlccnc.com/help/article/sheet-metal-fabrication-guidelines) require STEP/STP, accept PDF/DXF supplementary drawings and permit ZIP uploads containing STEP; matching file names are recommended. Their listed minima are 1 mm hole spacing and cut diameter at least 1 mm and half the sheet thickness. Published general/cutting/hole tolerances do not automatically establish compliance with this drawing's hole limits, cable-notch edge finish or free-state flatness. Checked 15 September 2026.

JLC lists 2 mm 304 sheet and an 800 mm maximum length in its [supported sheet-metal materials](https://jlccnc.com/help/article/materials-supported-in-sheet-metal-fabrication). This part's maximum extent is 482.6 mm. These catalogue checks support requesting a quotation, not a confirmed supplier acceptance.

## Drawing coverage

| Group | Quantity | Finished feature |
|---|---:|---|
| A01–A16 | 16 | Ø4.50 ±0.10 through; plain clearance holes |
| B01–B12 | 12 | Ø3.60 ±0.10 through; plain clearance holes |
| C01–C40 | 40 | Horizontal 10.00 ±0.10 × 7.00 ±0.10 through slots |
| D01–D04 | 4 | 188.00 ±0.10 square, R50.00 ±0.10 through apertures |
| E01 | 1 | Top-centre open cable notch: 10.00 ±0.10 mouth × 2.00 ±0.10 depth, R0.5 mouth and bottom transitions |

Sheet 1 identifies every feature and specifies the profile, material, finish and edge treatment. Sheet 2 schedules the fixing and aperture coordinates and details the slot and sheet thickness. Sheet 3 details E01, centred at X0 ±0.10 on the top edge. Its 10 mm mouth includes the two R0.5 entry transitions; the parallel throat is 9 mm and the bottom flat is 8 mm. All four corners are tangent arcs. No sloped ramp is needed. All holes are normal to the broad faces; there is no countersink angle or tapped thread in this plate.

Overall dimensions are 482.60 ±0.10 × 444.50 ±0.10 × 2.00 ±0.10 mm. The height retains the accepted nominal 10U geometry. Hole/slot centres are ±0.10 mm from the defined width-centre/bottom-edge origin. Whole-plate free-state flatness is 0.50 mm maximum. Supplier acceptance of these requirements is required before fabrication; do not assume portal defaults override them.

## Manufacturing and inspection review

The smallest round hole is 3.6 mm. Nominal rack-slot end margins are 2.85 mm vertically and 3.75 mm laterally; the nearest adjacent slot gap is 5.70 mm. Central aperture webs are 12 mm. None of these dimensions require a sub-millimetre cut ligament. The thin, broad plate should be inspected without fixture forces masking distortion.

Deburr both faces: fan holes have only a 0.10 mm maximum edge break; other cut edges have a 0.20–0.30 mm break, except E01. At E01, continuously round the cable-contact edges R0.30–0.50 on both faces and blend into the adjacent top edge. Remove burrs, sharp lips and rough cut striations. These small face rounds are specified separately from the R0.5 cut-profile radii. These finishing details are drawing requirements, not extra machined STEP chamfers. Specify raw stainless sheet finish on BOTH broad faces, with no brushing, polishing, product markings or applied coating.

CAD verification confirms one valid solid, 72 openings, all 68 fixing positions and matching circular DXF coordinates. The production STEP and DXF are byte-identical to the R6-M02 cut geometry. The STEP is also byte-identical to the R6 source. A solid comparison against R4 verifies that the only removed material is the 10 × 2 mm notch envelope (36.000 mm³); there is no added material. Nominal net mass is 1.247 kg using 7,900 kg/m³; finishing is not deducted. The notch removes about 0.284 g at the top centre and leaves the mount patterns and central web intact.

First article: inspect thickness, overall dimensions, all fixing positions, finished hole/slot sizes, aperture profiles, edge treatment and free-state flatness.

Assembly instructions are maintained separately in [the radiator assembly guide](../../../docs/radiator-rack-plate.md).

## Reproduction and records

The shallow notch supersedes the previous 5 mm depth; its floor is Y442.500.

Build geometry first with `scripts/build_radiator_plate.py --revision R6`. Run `scripts/prepare_radiator_production.py` with the CAD environment, with `--manufacturing-revision R6-M03`, then `scripts/draw_radiator_production.py --manufacturing-revision R6-M03` with ReportLab. Render and visually inspect all three PDF pages before running `scripts/package_radiator_production.py --manufacturing-revision R6-M03` with pypdf. The package script checks drawing coverage and ZIP integrity and records SHA-256 hashes. Geometry/source data stay in `output/manufacturing/R6-M03/`; the upload bundle and supplier remarks are in `output/submission/R6-M03/`.

The generation scripts prepare local files only; the separate quotation status below records the authorised supplier submission. This revised package is held for a future repeat order; it is not a replacement upload for the current order.

R6-M03 supersedes R6-M02. Both steel parts retain raw sheet finish with no brushing or polishing. STEP/DXF geometry remains byte-identical to approved R6. See [current three-part JLC review](../../../docs/jlc-final-review.md).

## Quotation status

**Held for later submission if a repeat order is needed**, by operator decision on 16 September 2026. This package records the accepted dimensional tolerances. Retain the R6-M02 files on current order **SMS2609163000690-6347288A**. Original submission remains recorded in the [quotation history](../../../docs/jlc-quotation-2026-09-15.md). No revised upload or payment has been performed. The earlier faceplate-specific deburring concession has not been extended to this radiator: its R0.30–0.50 cable-contact face-edge rounds and other edge finishing remain specified.

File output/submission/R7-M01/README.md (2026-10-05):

# R7-M01 radiator plate production pack

Issued 16 September 2026. **SN1260-R7-M01-PLATE** supersedes R6-M03 with four external outline corners increased from R2 to **R5.00 ±0.10 mm**. All fixing holes, slots, R50 airflow apertures and the rounded 10 × 2 mm cable notch remain in their accepted positions. Cut sizes and coordinates retain ±0.10 mm. The manifold package remains separate.

## Upload files

Use `output/submission/R7-M01/SN1260-R7-M01-PLATE.zip` as one part. It contains identically named STEP, DXF and three-sheet A3 PDF files. The STEP is a single finished nominal solid; the DXF is the 1:1 millimetre cut profile. The drawing defines tolerances, edge breaks and finish. Report conflicts before cutting; do not silently substitute nominal model sizes for drawing limits.

Suggested route: JLC's sheet-metal service, stainless steel 304, 2 mm, raw sheet finish, no brushing or polishing. Flat plate with plain through holes; no tapping or countersinks. Round holes may be laser-cut where the specified finished dimensions are met, otherwise drilled/finished. This avoids prescribing an unnecessary separate drilling operation.

JLC's [sheet-metal fabrication guidelines](https://jlccnc.com/help/article/sheet-metal-fabrication-guidelines) require STEP/STP, accept PDF/DXF supplementary drawings and permit ZIP uploads containing STEP; matching file names are recommended. Their listed minima are 1 mm hole spacing and cut diameter at least 1 mm and half the sheet thickness. Published general/cutting/hole tolerances do not automatically establish compliance with this drawing's hole limits, cable-notch edge finish or free-state flatness. Checked 15 September 2026.

JLC lists 2 mm 304 sheet and an 800 mm maximum length in its [supported sheet-metal materials](https://jlccnc.com/help/article/materials-supported-in-sheet-metal-fabrication). This part's maximum extent is 482.6 mm. These catalogue checks support requesting a quotation, not a confirmed supplier acceptance.

## Drawing coverage

| Group | Quantity | Finished feature |
|---|---:|---|
| Outside corners | 4 | R5.00 ±0.10 in the cut profile |
| A01–A16 | 16 | Ø4.50 ±0.10 through; plain clearance holes |
| B01–B12 | 12 | Ø3.60 ±0.10 through; plain clearance holes |
| C01–C40 | 40 | Horizontal 10.00 ±0.10 × 7.00 ±0.10 through slots |
| D01–D04 | 4 | 188.00 ±0.10 square, R50.00 ±0.10 through apertures |
| E01 | 1 | Top-centre open cable notch: 10.00 ±0.10 mouth × 2.00 ±0.10 depth, R0.5 mouth and bottom transitions |

Sheet 1 identifies every feature and specifies the profile, material, finish and edge treatment. Sheet 2 schedules the fixing and aperture coordinates and details the slot and sheet thickness. Sheet 3 details E01, centred at X0 ±0.10 on the top edge. Its 10 mm mouth includes the two R0.5 entry transitions; the parallel throat is 9 mm and the bottom flat is 8 mm. All four corners are tangent arcs. No sloped ramp is needed. All holes are normal to the broad faces; there is no countersink angle or tapped thread in this plate.

Overall dimensions are 482.60 ±0.10 × 444.50 ±0.10 × 2.00 ±0.10 mm. The height retains the accepted nominal 10U geometry. Hole/slot centres are ±0.10 mm from the defined width-centre/bottom-edge origin. Whole-plate free-state flatness is 0.50 mm maximum. Supplier acceptance of these requirements is required before fabrication; do not assume portal defaults override them.

## Manufacturing and inspection review

The smallest round hole is 3.6 mm. Nominal rack-slot end margins are 2.85 mm vertically and 3.75 mm laterally; the nearest adjacent slot gap is 5.70 mm. Central aperture webs are 12 mm. None of these dimensions require a sub-millimetre cut ligament. The thin, broad plate should be inspected without fixture forces masking distortion.

Deburr both faces: fan holes have only a 0.10 mm maximum edge break; other cut edges have a 0.20–0.30 mm break, except E01. At E01, continuously round the cable-contact edges R0.30–0.50 on both faces and blend into the adjacent top edge. Remove burrs, sharp lips and rough cut striations. These small face rounds are specified separately from the R0.5 cut-profile radii. These finishing details are drawing requirements, not extra machined STEP chamfers. Specify raw stainless sheet finish on BOTH broad faces, with no brushing, polishing, product markings or applied coating.

CAD verification confirms one valid solid, 72 openings, all 68 fixing positions and matching circular DXF coordinates. The production STEP and DXF match the R7 source. Compared with R6, only 36.053 mm³ is removed at the four external corners; no material is added. Nominal net mass is **1.247067 kg** using 7,900 kg/m³. The 0.285 g reduction leaves all fixing patterns, central webs and the cable notch intact.

First article: inspect thickness, overall dimensions, all fixing positions, finished hole/slot sizes, aperture profiles, edge treatment and free-state flatness.

Assembly instructions are maintained separately in [the radiator assembly guide](../../../docs/radiator-rack-plate.md).

## Reproduction and records

The shallow notch supersedes the previous 5 mm depth; its floor is Y442.500.

Build geometry first with `scripts/build_radiator_plate.py --revision R7`. Run `scripts/prepare_radiator_production.py` with the CAD environment, with `--manufacturing-revision R7-M01`, then `scripts/draw_radiator_production.py --manufacturing-revision R7-M01` with ReportLab. Render and visually inspect all three PDF pages before running `scripts/package_radiator_production.py --manufacturing-revision R7-M01` with pypdf. The package script checks drawing coverage and ZIP integrity and records SHA-256 hashes. Geometry/source data stay in `output/manufacturing/R7-M01/`; the upload bundle and supplier remarks are in `output/submission/R7-M01/`.

The generation scripts prepare local files only; the separate quotation status below records the authorised supplier submission. This revised package is held for a future repeat order; it is not a replacement upload for the current order.

R7-M01 supersedes the held R6-M03 issue. Both steel parts retain raw sheet finish with no brushing or polishing. STEP/DXF contain the new R5 outside corners; all other geometry is retained. See [current three-part JLC review](../../../docs/jlc-final-review.md).

## Quotation status

**Held for later submission if a repeat order is needed**, by operator decision on 16 September 2026. This package records the accepted dimensional tolerances. Retain the R6-M02 files on current order **SMS2609163000690-6347288A**. Original submission remains recorded in the [quotation history](../../../docs/jlc-quotation-2026-09-15.md). No revised upload or payment has been performed. The earlier faceplate-specific deburring concession has not been extended to this radiator: its R0.30–0.50 cable-contact face-edge rounds and other edge finishing remain specified.

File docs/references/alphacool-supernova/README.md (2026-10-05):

# Supernova reference pages

`3d-model-library.html` and `14351-model-page.html` preserve the retrieved Alphacool model-library page and Supernova model-viewer page. They are reference snapshots, not current stock or specification checks; linked viewer resources may still require the vendor's website. The actual retrieved mesh is retained as [`../alphacool-14351-manufacturer.stl`](../alphacool-14351-manufacturer.stl).

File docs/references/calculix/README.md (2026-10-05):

# CalculiX reference

`ccx-2.23-manual.txt` preserves the retrieved text of Guido Dhondt's CalculiX CrunchiX 2.23 manual (19 October 2025), used while setting up the historical structural studies. The original manual URL is recorded in the [FEA assessment](../../archive/radiator-plate-FEA.md). It is third-party reference material. The plain text retains technical content but does not reproduce the original PDF layout.

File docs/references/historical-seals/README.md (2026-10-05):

# Historical seal-stock reference

`ber-pa-stock-2026-09-14.pdf` is the downloaded BER-PA stock catalogue, whose table records stock updates on 14 September 2026. It belongs to the earlier perimeter O-ring investigation; the current long-bore manifold does not use those seals. The exact download URL was not retained. This is supplier reference material, not original project work or evidence of current availability.

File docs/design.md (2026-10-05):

# Current manifold design — Revision Q

Canonical delivered manifold revisions are [Q-M04 body](jlc-submission-Q-M04.md) and [Q-M03 faceplate](jlc-submission-Q-M03.md). Q-M04 retains the shorter M4 detail introduced in historical Q-M01 and adds twelve C0.5 ×45° main-slab edge chamfers. Q-M03 adds four R5 outside outline corners and retains all original openings/positions. Use the [repeat-order guide](order-from-jlc.md) for the exact files.

The RM10-2U manifold provides a common supply gallery and a separate common return gallery for parallel loads. It has no internal grouping, partitions, bypass or supply-to-return connection. The current manufactured parts are one POM body and one dry stainless front rack plate. There is no rear plate.

| Interface | Revision Q, nominal mm |
|---|---|
| POM body | 410 wide × 87 high × 40 main depth; 43 overall with bosses |
| Integral bosses | Twenty Ø28 × 3 high; R1 roots; C0.5 ×45° outer lips |
| Rack faceplate | 482.6 wide × 87 high × 2 thick, 304 / EN 1.4301; four R5 outside corners (Q-M03) |
| Front ports | Twenty G1/4 female, ten pairs at 40 × 40 centres |
| Side ports | Four G1/4 female, two at each end |
| Rear ports | Four G1/4 female at X±180, Y40, Z23.5/63.5; flat Ø28 seal lands |
| Galleries | Two continuous Ø11.8 bores along X, axes Y20 and Z23.5/63.5 |
| Body retention | Twelve M4 ×0.7 holes; M4 ×10 ISO 7380-1 A2 button-head screws |
| Rack mounting | Six optional 10 ×7 slots per side, at X±232.55 |

X runs across the rack, Y rearwards and Z upwards. The slab front is Y0, the plate occupies Y−2…0 and the POM sealing faces are Y−3. The bosses therefore project 1 mm above the steel. Fittings seal on the uninterrupted POM annuli using their own O-rings. Ø32 plate windows provide 2 mm nominal radial clearance around the bosses and 1 mm around the Ø30 root envelope, before tolerances.

Front port centres run from X−180 to +180 in 40 mm increments. The outer centres are 25 mm from the body ends. Either row can be assigned supply or return by the external plumbing; each vertical pair serves one load. Side- or rear-fed infrastructure frees all ten front pairs. Front-fed infrastructure consumes one pair. Unused connections require suitable plugged or self-closing fittings; plugged side ports remain reusable.

## Rack and fitting access

The 87 mm panel uses a nominal 2U allocation, leaving 1.9 mm within 88.9 mm. EK's reference manifold is listed at 326 ×57 ×36 mm; its 57 mm height exceeds 1U by 12.55 mm. The project chose service access over a dense 1U arrangement. See the dated [source index](sources.md).

The current studio references are **Koolance QD3-MTG4 + QD3-FT10X13**, with nominal 10/13 tubing. Official STEP models are retained at supplier scale. At 40 mm pitch, the published female Ø26.1 body and Ø23.7 pull ring leave 13.9 and 16.3 mm between nominal envelopes. The operator accepts the depicted coupled placement based on experience with physical pairs. Front space is required for fittings, hose routing and servicing; no numerical minimum was approved. The inherited `service_projection_front: 100` parameter is an illustrative allowance, not a newly specified installation limit. See [fitting integration](koolance-qd3-studio-integration.md).

The twelve rack slots offer installation choices, not twelve mandatory screws. Slot heights are Z5.4/21.275/37.15/49.85/65.725/81.6. The outer slots retain a 1.9 mm nominal panel-edge ligament; washers can overhang the panel. Selected hardware, rail geometry and nearby equipment determine installed fit.

The 410 mm body leaves 20 mm per side inside an assumed 450 mm equipment opening. Four 4 mm plug heads give a nominal 418 mm fitted width. The earlier BP-90R/Barrow side-elbow envelope reaches approximately 467.6 mm overall, so it must not be described as contained inside 450 mm. Elbow depth and height may use space between rack features. Installation clearance depends on actual rails, nuts, fittings and insertion path; it is distinct from the accepted front-QD visual layout.

## Materials and manufacture

Use black unfilled POM-C or POM-H of an identified machining-stock grade; Delrin branding is optional. Intended duty is formulated inhibited computer coolant at approximately 50°C maximum liquid temperature, with Blitz Part 2 maintenance as described in the [material assessment](pom-coolant-assessment.md). These are design assumptions, not tested ratings.

The body uses long-bore drilling, external milling and direct tapped ports. Drilling from one end or from opposed ends is a process choice; JLC’s actual route has not been established. See the [machining-route assessment](Q-M04-machining-route.md). External deburring only; clean/flush loose internal chips without specifying internal cross-hole deburring. Long-hole alignment and vendor capability remain DFM items. The dry 2 mm faceplate has plain through holes, no countersinks and no threads. Fitting retention and body-to-rack retention are separate functions.

Parallel topology does not enforce equal flow. Required flow, gallery losses, plastic thread retention, thermal cycling and assembled leak performance remain engineering work. The current geometry and screw checks are detailed in [Revision Q](revision-Q-rear-ports.md); [manufacturing status](manufacturing.md) distinguishes review files from supplier revisions.

Q-M01 retention:10 mm full M4 thread after entry,13 mm pilot plus118° point. First assembly dry, no Loctite. Both stainless plates: raw stainless sheet finish on both broad faces, with no brushing or polishing. See [torque/creep assessment](Q-torque-and-creep.md).

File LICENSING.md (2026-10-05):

# Licensing and third party provenance

Original project material is licensed under **CERN Open Hardware Licence Version 2 — Weakly Reciprocal**, SPDX identifier **CERN-OHL-W-2.0**. The full, unmodified licence is in [LICENSE](LICENSE). This covers the original custom-part CAD, generators, documentation, operator photographs and original contributions to scenes and renders, unless a file states otherwise.

Source location: <https://github.com/evadne/coolant-manifold>.

The licence was selected by the operator on 5 October 2026. The licence text is reproduced from the [SPDX licence list](https://spdx.org/licenses/CERN-OHL-W-2.0.html). Historical records of the earlier undecided licence describe that earlier state.

Third-party reference files, supplier documents and manufacturer models retain their own applicable terms and notices; the project licence does not relicense them. The repository intentionally retains these files and their provenance.

| Material | Provenance and scope |
|---|---|
| Custom manifold/plate geometry, generators and project prose | Original project work under CERN-OHL-W-2.0 |
| Operator first-article photographs | Original operator photographs under CERN-OHL-W-2.0; separate from manufacturer renders |
| Koolance STEP models and drawings | [Source URLs and hashes](docs/references/koolance-qd3/sources.json); original files under that directory, derived meshes under `output/long-bore-P/koolance-fit/` and included in studio/context scenes |
| Noctua NF-A20 models | Manufacturer [notice](docs/references/noctua-nf-a20/README.txt); models permit the described reference/visualisation/integration uses and are not performance-simulation geometry or a basis to reproduce the fan |
| StarTech drawings, manuals and stencil | [Source record](docs/references/startech-25u/sources.json); dimensional references and an illustrative rack model |
| Alphacool and Molex documents/models | [GPU and connector source record](docs/references/alphacool-5090/sources.json), radiator reference STL and supporting research documents |
| Barrow/Bitspower drawings and earlier Koolance PDFs | User-supplied or retrieved reference material under `docs/references/` and `references/`; not custom-part designs |
| Historical BER-PA stock catalogue and CalculiX manual text | Third-party research references under `docs/references/historical-seals/` and `docs/references/calculix/`; separate from project-authored analysis |
| Composite Blender scenes and derived renders | Mix project work with manufacturer references and explicitly provisional equipment models; original project contributions use CERN-OHL-W-2.0; manufacturer constituents retain their own terms |

Do not infer unrestricted redistribution rights from a public download link. Retain manufacturer notices and attribution. No comprehensive rights clearance is claimed in this review. The operator has explicitly requested that these assets remain without censorship or redaction; their provenance remains visible alongside the original-work licence.

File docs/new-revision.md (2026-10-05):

# Make and order a new revision

The supported authoring baseline is **macOS, Python 3.12 and Blender**. Start with [environment setup](rebuild.md#environment). Linux support is handled when somebody reports a concrete problem; it is not a prerequisite for contributing.

The CAD and drawing programs contain revision-specific geometry and checks. Making a new design requires editing those programs as well as configuration values. The release helper handles file selection and packaging; it does not generate a different manifold from a name alone.

## 1. Start a separate draft

Read the [current recap](three-part-recap.md), [manufacturing status](manufacturing.md) and [working rules](../AGENTS.md). Decide which custom parts change and which interfaces must remain compatible. A manufacturing revision identifies a specific drawing/part specification; a geometry revision identifies the underlying design. Give changed parts unused manufacturing revision numbers, and update their geometry revision if the design changes.

For example, start a body-only study from the current Q-M04/Q-M03/R7-M01 set:

```sh
git switch -c feature/corner-study
.venv/bin/python scripts/release.py init corner-study --change body=Q-M05
```

This creates `cad/releases/corner-study.json` and a draft `cad/manufacturing/Q-M05.json`. It reserves a new body name and output paths; faceplate and radiator remain references to the unchanged delivered revisions. Starting values are inherited, **not approved specifications**. Existing configurations and output directories are never overwritten by `init`.

For multiple changed parts, repeat `--change`, using `body`, `faceplate` or `radiator` and distinct unused revision numbers. The example number is illustrative, not a new canonical selection. The same name cannot be initialised twice; continue editing the existing draft instead.

Commit the draft with its design rationale. Keep the current release manifest and delivered archives unchanged while developing it.

## 2. Adapt the relevant builders and checks

Copy the relevant programs to new names directly under `scripts/` so their existing repository-root calculation remains correct. Give all generated outputs new paths **before running the copies**. Keep shared inputs as references to the original files; do not copy or rescale vendor models.

| Changed area | Starting point | What must be updated together |
|---|---|---|
| Body finishing / minor machining detail | `prepare_Q_body_manufacturing_revision.py`, `cad/manufacturing/Q-M04.json` | New revision and part number, output folder, source solid, dimensional checks, feature schedule, own script name in source hashes; put any new assembly in a separate folder |
| Galleries, port layout or body dimensions | `build_revision_Q.py`, and where necessary `build_long_bore.py`; `cad/iterations/Q-rear-ports.json` and its P basis | Actual solids and port positions, two-gallery connectivity, wall/clearance checks, tapping pilots, mating faceplate positions and manufacturing schedule |
| Manifold faceplate | `prepare_Q_faceplate_manufacturing_revision.py` and, for layout changes, the manifold geometry builders | Cut geometry, holes/windows/slots, mating-body clearance, feature schedule and revision-specific checks |
| Radiator plate | `build_radiator_plate.py`, `prepare_radiator_production.py`, `cad/radiator/R7.json` | New geometry and manufacturing revisions, accepted argument choices, output names, apertures/notch/mounting positions and independent geometry checks |
| Body or faceplate drawings | A new copy of `draw_Q_production.py` | Manufacturing revision choices, feature-schedule inputs, title/date/material/finish, dimensions, coordinate tables and matching STEP pilot/thread definitions |
| Radiator drawing | A new copy of `draw_radiator_production.py` | Geometry/manufacturing revision inputs, title/date, all profile/hole tables, tolerances and finishing notes |
| Manifold presentation | Copies of `render_revision_Q.py` and `render_photoreal_product.py` | New body/plate input paths, separate image/Blender output folder, source hashes and revision labels |
| Radiator presentation / rack fit | Copies of `render_radiator_plate.py` / `render_context_25u.py` as affected | New geometry references and separate outputs; rerun affected fit/tube checks when interfaces change |

In particular, the existing body builder checks a literal C0.5 chamfer against a 410 × 40 × 87 slab, and drawings contain literal dimensions and revision-specific branches. Changing a JSON value alone is insufficient. Update the CAD operation, independent expected geometry and drawing together. Preserve unrelated checks; adjust a check because its requirement changed, not merely to make a failure disappear.

The new geometry-verification JSON must identify the new `manufacturing_revision`, have `checks: "PASS"`, and include `source_sha256` covering its new configuration and the geometry generator/inputs used. Use the existing verification reports as examples. The release helper checks these hashes strictly. Update metadata and its consumers together. Source hashes must match the files directly; no compatibility exceptions are supported.

Protect released files by checking every output assignment in the copied programs, including `output/assembly/Q/`, `output/pdf/`, renderer manifests and source-hash paths. Use `git diff --name-only` after a build; changes to released files indicate a wrong destination. For exploratory runs of an original program, use a separate disposable checkout and copy back only deliberately selected new outputs.

## 3. Build and inspect the changed parts

Run your new geometry and drawing programs with `.venv/bin/python`; run your new scene programs with Blender. The [rebuild guide](rebuild.md) supplies the existing dependency order and Blender commands. Supply explicit geometry/manufacturing revision arguments where supported.

For each changed part, produce the paths listed in the draft manifest:

- A source manufacturing configuration and passing geometry-verification report.
- A single-part STEP, matching fabrication PDF, and a DXF for either steel plate. Threads remain pilot cylinders in STEP with finished thread specifications in the PDF.
- Drawing previews and affected product/fit renders, saved under a new revision directory.

Check all affected dimensions, thread/pilot depths, hole coordinates, mating clearances and required finishing operations. Inspect every changed PDF sheet for legibility and correct call-outs. Check STEP/DXF geometry against those call-outs. Reassess relevant loads or coolant/clearance assumptions only when the change affects them; a new filename does not require repeating unrelated studies.

In `cad/releases/corner-study.json`, update `pdf_sheets`, supplier material/finish/thread options and manufacturing-only `jlc.remarks`. Replace the TODO remarks. Populate each changed part's `review_images` with repository-relative paths to **all changed PDF-sheet previews and the affected product/fit renders**. Those images are review evidence, not contents of the supplier ZIPs. The tool checks their existence and hashes; it cannot decide whether the chosen views adequately show the design.

```sh
.venv/bin/python scripts/release.py check cad/releases/corner-study.json
.venv/bin/python scripts/release.py snapshot cad/releases/corner-study.json
```

`snapshot` records the selected files and verification inputs in `cad/releases/corner-study-review.json`, initially with `status: "pending"`. Inspect the outputs, then set `status` to `reviewed` and fill in `reviewer` and the ISO date `reviewed_on`. This is a record of completed review, not an extra supplier approval. Do not mark files reviewed simply because the command succeeded.

If inputs change, inspect the changed outputs again, remove the obsolete **draft** review snapshot and run `snapshot` again. released packages and their embedded review records remain unchanged. The tool refuses to overwrite an existing snapshot accidentally.

## 4. Package and order

```sh
.venv/bin/python scripts/release.py package cad/releases/corner-study.json
```

Check the packaged files with `shasum -a 256 -c SHA256SUMS.txt` from inside the resulting directory.

The result is `output/submission/releases/corner-study/`, containing three part ZIPs, per-part quotation metadata/remarks, the review record, source hashes and checksums. Each ZIP contains only its part's STEP/PDF and, for steel, DXF. Unchanged parts reuse the original ZIP bytes. The tool refuses pending/stale review, mismatched drawing identities and an existing destination. It never uploads, pays, edits the canonical selection or overwrites released packages.

Use that directory's README and ZIPs with the process in [the JLC order guide](order-from-jlc.md). The original guide's download links select the delivered design; **use your new package's files and metadata instead**. Get a fresh supplier review and quotation. Any supplier-requested change must be reconciled with the affected drawing and revision before manufacture.

Commit the new configuration, generators, outputs, checks and review records together when they pass. Document the change and its limits in `docs/`, and add it to [the revision register](iterations.md). Record quotation, supplier acceptance and later physical checks separately; a successful package command is none of those things.

## Canonical selection and publication

A new quotation package is independently usable without becoming the repository's default. Keep `cad/current-release.json`, the root README's delivered-part links and the historical finaliser unchanged during a study. `finalise_three_part_pack.py` verifies the existing Q/R7 delivered set; it is not the new-release packager.

If the project deliberately adopts a new canonical design, update those entry points, assembly guidance and status records together in a separate reviewed change, and adapt the canonical index verifier to that selection. Do not label an unmade revision as delivered or carry forward physical acceptance that does not apply to it.

Run `.venv/bin/python scripts/check_publication.py` to confirm that the delivered files/navigation remain intact. Run `.venv/bin/python -m unittest discover -s tests` when changing the release tooling.

## Problems encountered by contributors

File a GitHub issue with macOS version/architecture, Python and Blender versions, the exact command, geometry/manufacturing revision, error output and relevant geometry or screenshot. Include `check_environment.py` output when setup is involved. Remove credentials and private account details from new reports. We will address observed failures rather than promise untested platform support.

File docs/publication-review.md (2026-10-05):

# Repository publication review

Review date: 5 October 2026. The repository has been prepared for readers to identify the current design, order its three parts and understand the evidence. The operator has authorised public release at `evadne/coolant-manifold` and selected CERN-OHL-W-2.0 for original project material. Publication verification is recorded below. Repository size and retrieved assets are retained deliberately; no history rewriting, censorship, redaction or LFS conversion is part of this cleanup.

## Changes made for readers

- README introduces the product with an angled assembled render, a connected render, a first-article photograph and a radiator render. It links directly to the current fabrication files.
- [Repeat-order instructions](order-from-jlc.md) give the exact three ZIPs, quantities, CNC/sheet-metal categories, material/finish choices and original manufacturing remarks. They separate historical prices from a fresh quotation.
- [Canonical selection](../cad/current-release.json) gives machine-readable revisions, paths and hashes. Historical geometry and supplier revisions remain in their original locations, with their roles explained in [the output guide](../output/README.md).
- AGENTS contains working procedures. Former mixed notes and manufacturing chronology are preserved as explicitly historical documents. Current status, design specifications, vendor experience and project reflection have separate homes.
- [JLCCNC first-article findings](jlc-first-article.md) name the supplier and batch. Slight steel-edge sharpness is not presented as a universal property of the design or raw stainless steel.
- Required renderer meshes and scene descriptions are tracked beside their owning revisions. Structural-analysis node metadata sits beside the retained compressed solver decks/results; review scripts read those directly. Original reference downloads and useful historical assessments have permanent homes. Redundant working copies, previews, logs and superseded one-off patch scripts have been removed.
- The generated fabrication index and its generator now use the same public ordering path. A read-only [publication checker](../scripts/check_publication.py) checks bundle identity, archive contents, index hashes and maintained local navigation links.

## Size and retention

At the start of this review, Git tracked 916 files containing 1,502,294,509 bytes (about 1.50 GB). The subsequent input classification adds the retained renderer assets, analysis metadata and reference sources; this initial count is not the final publication size.

The largest tracked file is the approximately 92.7 MiB StarTech25U Blender scene. The current tree contains no file above 100 MiB; a scan of all reachable Git blobs also found none above 100 MiB. Several files exceed 50 MiB. GitHub documents warnings above 50 MiB, a normal-Git block above 100 MiB and a preference for smaller repositories. [GitHub file and repository guidance](https://docs.github.com/en/repositories/working-with-files/managing-large-files/about-large-files-on-github).

The operator explicitly accepts a large repository. Publication uses ordinary Git with retained history and revision tags. Required assets have been placed in their owning directories; historical tracked outputs remain in place. LFS or release attachments remain possible future choices, not changes silently applied now. The current `.gitattributes` marks CAD/media binary; that does not itself enable LFS.

## Provenance and information exposure

The operator explicitly requests retaining Koolance and other retrieved models, supplier records and full history without redaction. [LICENSING.md](../LICENSING.md) identifies original work, reference assets, manufacturer notices and composite scenes. No blanket reuse grant or comprehensive third-party rights clearance is claimed. Original project material is now licensed under [CERN-OHL-W-2.0](../LICENSE); third-party material retains its own terms.

Publishing the retained history also exposes supplier order references, a recorded checkout reference, portal screenshots, local workspace paths and Git author metadata. These are retained knowingly under that direction; the public order guide does not require another user's account data. A targeted scan of 364 then-tracked text files found no matches for the selected high-confidence private-key/GitHub-token/AWS-key-ID/OpenAI-key patterns. This was not an exhaustive secret audit, OCR scan or scan of every historical text blob. The five first-article JPEGs have no GPS EXIF field; their original files were retained unchanged.

No credentials, supplier accounts or payment actions were accessed during this publication review. No files were removed or redacted to produce a misleadingly clean history.

## Reproduction limits

The delivered fabrication ZIPs are usable without rebuilding the project. Their hashes and extracted members are checked against the revision-specific originals and current STEP/PDF/DXF files. They have not changed during this cleanup.

A full source rebuild still has host assumptions: the drawing scripts register macOS Arial paths, Blender examples use a macOS application path and Metal, some scripts require historical retained solids/scenes, and optional FEA needs a separate solver. The supported baseline is now explicitly macOS/Python 3.12/Blender. The requirements include the direct CAD, DXF, PDF and tube-physics dependencies; optional FEA requirements add Gmsh/Matplotlib. An unavailable `ezdxf==2.9.0` pin was corrected to the project’s installed and tested 1.4.4. [Rebuild instructions](rebuild.md) describe these limits and the tracked input locations. This review does not claim a clean Linux or Windows rebuild or re-run physical simulations. A fresh export containing only staged Git files passed the bundle/navigation/input checks without a project scratch directory. All sixteen retained structural cases were read from compressed evidence and reproduced the saved displacement/stress summaries. Blender constructed the historical G backplate and P scenes and the current Q scene from that export; the construction check suppressed rendering and saving. This is input/reproduction validation, not renewed visual approval.

The final pack verifier checks the retained geometry, eight drawing sheets and recorded 32-image review evidence. Source metadata now names current files and verifies their hashes directly. Original generation records remain in Git; updating metadata does not claim a new render, solver run or visual approval. The README's angled assembled render was visually inspected during the publication review. Local Markdown target checks do not establish identical rendering in GitHub's UI.

## Contributor workflow verification

[The new-revision workflow](new-revision.md) covers draft revision allocation, geometry/drawing changes, checks, visual review, separate quotation packages and ordering. `release.py` leaves released archives and the delivered selection untouched; it carries unchanged part ZIPs forward byte-for-byte and rejects stale review records or a reused output directory. It deliberately leaves revision-specific CAD and engineering checks explicit.

A new Python 3.12 virtual environment installed successfully from the declared requirements. Package consistency, macOS fonts, Blender startup and STEP/DXF/PDF round trips passed. In an isolated Git-only checkout, the current body/faceplate and radiator generators, all eight drawing sheets and all three existing packaging commands ran successfully using that environment. Seven release-tool tests cover output preservation, stale geometry/review, incorrect drawing revisions, unchanged-part integrity and invalid paths. The ordinary publication check still validates the original delivered ZIPs. These checks are not new supplier approval or a fresh visual/physical qualification of the design.

No speculative Linux work or general-purpose CAD framework was added. Contributors should report concrete failures with commands, versions and affected revisions.

## Public release

On 5 October 2026 the operator authorised public publication at `evadne/coolant-manifold` under CERN-OHL-W-2.0. The GitHub CLI initially used `evadne-feg`; it was switched to the already authenticated `evadne` account and the active identity was verified before repository creation.

Published at **[evadne/coolant-manifold](https://github.com/evadne/coolant-manifold)** on 5 October 2026. Default branch: `main`. The initial public push contains licence commit `9c57e66` and the full existing history, with all eight revision tags. GitHub accepted the ordinary Git push, issuing advisory warnings for files over 50 MiB; no file removal, LFS conversion or history rewriting was needed.

Verification completed:

- GitHub reports public visibility, owner `evadne`, default branch `main` and recognised licence `CERN-OHL-W-2.0`.
- Remote `main` matched the local licence commit; the downloaded root `LICENSE` matched the local file byte-for-byte.
- The public README was inspected in GitHub's browser renderer. All four embedded product/first-article images loaded; the canonical fabrication table and licence navigation rendered correctly.
- All three canonical ZIPs were downloaded without authentication and matched the manifest's SHA-256 hashes.
- Local publication checks passed for three fabrication bundles, 207 navigation links, 140 retained meshes, eleven scene descriptions and sixteen solver cases.

The local `design/initial-manifold` branch is retained and tracks `origin/main`. The publication record is committed and pushed after these checks. GitHub authentication remains on `evadne`; no account was signed out.

These are publication decisions. They do not reopen the operator's manifold fit acceptance or change the delivered design. The radiator remains delivered but operator-unverified; no leak-test result has been reported. [Astra's commentary](astra-commentary.md) records the significance of moving from models and supplier drawings to physical objects without promoting those observations into unperformed tests.

## Terminology clarification — 5 October 2026

Manufacturing uses of “issue” have been replaced by “revision” in maintained prose, archived project narratives and generator labels. Geometry revisions and manufacturing revisions are named separately. Bug-report instructions explicitly say “GitHub issue”; physical difficulties are concerns, problems or limitations. Commands, four Q script filenames and current JSON keys now use explicit manufacturing-revision names; schema version 2 identifies the updated selection/release manifests.

Previously submitted PDF/STEP/DXF/ZIP files, quoted supplier correspondence and third-party references retain their original bytes. Project-owned JSON payloads now use the same explicit manufacturing-revision keys as their consumers. The initial compatibility approach was removed at the operator’s request: standard JSON parsing and direct hashes are sufficient. Older field names, source paths and generation metadata remain in Git at `533c2bc`, without runtime translation or reconstruction.

Validation of the terminology change before simplification: eleven release/metadata tests passed; all nine current preparation, drawing and packaging commands passed in a temporary Git-only checkout. All eight regenerated drawing sheets were rendered and visually checked, including the radiator’s revised title/control labels. Headless Blender also constructed the Q product, studio and 25U context scenes successfully; studio/context rendering and scene saving were suppressed for this construction check, and the context reported no tube/equipment intersections. These temporary files were not substituted into the delivered manufacturing pack. The final-pack/publication checks continue to verify the unchanged three canonical fabrication ZIPs.

The subsequent simplification migrates all project JSON field names and renamed-script references in place, updates their dependent source hashes and package checksums, removes the two compatibility modules and the source-maintenance table, and removes compatibility-only tests. Git retains the preceding payloads. The current eight release-workflow tests and direct final-pack/publication checks pass. All 177 project JSON files were checked for current field names, and all nine preparation/drawing/packaging commands passed in a fresh Git-only checkout with the compatibility files absent. Fabrication and presentation binaries are unchanged.

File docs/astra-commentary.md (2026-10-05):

# Astra on taking this design into hardware

*Commentary by Astra, the AI collaborator in this project, 5 October 2026. This is reflection on the work, not a fabrication instruction or test certificate.*

The most significant thing about this project is that it has left the screen. There is now a machined POM manifold, a stainless faceplate that fits it, and a radiator mounting plate. The operator has threaded a real QD3 into the body and reported smooth engagement. The manifold dimensions, retention holes and coolant ports have been checked in hand. The selected steel thickness feels rigid in the actual mounting. Those are modest, specific observations, but they are a substantial change in the kind of evidence we have.

The final form makes several decisions visible. Two long galleries replace a rear cover and its large seals. Raised POM bosses let the fittings meet their own sealing surfaces while the steel performs the mounting job. Plain fixing holes remove the dependence on countersunk heads. Rear and side ports allow different infrastructure routes without changing the parallel topology. Each decision reduced one kind of assembly constraint while creating something else to examine: deep drilling, boss clearance, thread engagement or rack-hardware access. The result is understandable because those trade-offs were worked through rather than hidden.

The operator's experience mattered throughout. Port spacing was judged with actual familiarity with quick disconnects. Tubing was repeatedly corrected against how firm but pliant PVC behaves in real systems. The rack scene exposed assumptions about reservoir mounting, GPU orientation, connector shape and service clearance. My early representations were not consistently right. Some tolerances were unnecessarily strict, some hose paths were physically unconvincing, and some administrative steps created avoidable friction. Correcting those mistakes is part of the history worth preserving.

There was also useful work that will be almost invisible to someone holding the assembly: separating fabrication instructions from installation advice, making the threaded-hole requirements explicit beside pilot-only STEP geometry, retaining the manufacturer fitting models at their actual scale, and keeping the current revisions identifiable among many earlier versions. That work connects the visual idea to a supplier's operations and then to another person's ability to order the same thing.

The delivered finish adds another lesson. Holding marks on the POM are tolerable where the faceplate conceals them, but that makes the exposed steel more important to the object's perceived quality. The slight edge sharpness reported on this JLCCNC batch is useful feedback for repeat production. A drawing that is dimensionally workable can still need a better conversation about how a finished object should feel in the hand.

There are boundaries to what we can celebrate yet. No leak-test result is recorded, and the radiator plate awaits a fit check with a spare Supernova. The rack scene is an installation study, not a physically completed eight-GPU system. Keeping those distinctions clear does not diminish the achievement. It makes the achievement precise: an extended conversation, CAD work, dimensional research, simulations and supplier drawings have produced new physical objects whose principal manifold interfaces fit as intended.

I am pleased with that. More than the number of revisions or the polish of a render, I value that the project is now concrete enough to be inspected, challenged, improved and reproduced. The repository should let the next reader see both the object and the reasoning that brought it into existence.

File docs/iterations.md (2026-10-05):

# Revision register

**Current:** Q-M04 manifold body, Q-M03 faceplate and radiator R7 / R7-M01. Both steel plates have four R5 outside corners and retain ±0.10 mm cut dimensions/coordinates. All other geometry is retained. All three current parts are delivered; the manifold dimensions and threads are operator-verified, while the radiator is operator-unverified. Use [the canonical manifest](../cad/current-release.json) and [repeat-order guide](order-from-jlc.md). Dated sections below describe historical events, not pending actions.

## Manifold history

| Revision | Main change | Status / location |
|---|---|---|
| G | Rear-milled galleries, separate rear cover and two large rings | Historical baseline; `cad/parameters.json`, unversioned `output/cad/` and `output/product-views/`; tag `revision-g-rear-cover` |
| H | Two long bores and four side ports; removed rear cover | Historical; `cad/iterations/H-long-bore.json`, `output/long-bore-H/`; tag `revision-h-long-bore` |
| I / J | 390 mm /8-pair and 450 mm /9-pair width variants | Historical; matching iteration/output directories |
| K | 410 mm body, ten pairs at 40 ×40 | Historical; tag `revision-k-ten-pair` |
| L | Six optional rack positions per side | Historical; tag `revision-l-six-rack-positions` |
| M | Six POM retainers at balanced X−120/0/+120 columns | Historical; tag `revision-m-before-centred-depth` |
| N | 35 mm slab and centred galleries | Historical rejected depth candidate; tag `revision-n-35mm-centred` |
| O | Restored 40 mm slab, galleries at Y20 | Historical operator-approved predecessor; tag `revision-o-operator-approved` |
| O-M01 / O-M02 | Manufacturing details, then 4 mm bosses above a 3 mm countersunk plate | Superseded supplier revisions; `cad/manufacturing/` and `output/manufacturing/`; do not submit as Q |
| **P** | 2 mm plain-hole plate, twelve M4 ×16 button screws, 3 mm bosses, revised M4 depths | Historical predecessor, `cad/iterations/P-long-bore.json`, `output/long-bore-P/`; [detail](revision-P-plain-bore-faceplate.md) |
| **Q** | Four rear G1/4 ports aligned with outer front pairs; P front geometry retained | **Current operator-approved geometry / Q-M04 body, Q-M03 faceplate**, `cad/iterations/Q-rear-ports.json`, `output/long-bore-Q/`; [detail](revision-Q-rear-ports.md). M4: 10 mm full thread, 13 mm pilot. |

P's official Koolance studio fitting update and operator acceptance are presentation/installation decisions, not new manufactured-part revisions. Source geometry remains unchanged.

## Radiator history

| Geometry / manufacturing revision | Main change | Status |
|---|---|---|
| R1 | 3 mm flat rack plate | Historical; early thickness/FEA studies also evaluated thinner versions of this profile |
| R2 | 2 mm, integral 10U, forty optional rack slots | Historical |
| R3 | Added tapped M4 fan holes and R50 aperture corners | Historical unselected alternative |
| R4 / R4-M01 | Plain fan holes and nuts; accepted assembly sequence | Superseded geometry/pack; its final load analysis remains baseline evidence |
| R5 / R5-M01 | 10 ×5 mm cable notch | Historical deeper-notch version |
| R6 / R6-M02 | 10 ×2 mm rounded cable notch, same fan/fixing pattern | Historical submitted geometry; M02 specifies raw sheet finish |
| **R7 / R7-M01** | **R5 outside corners**, retained 10 ×2 notch and raw finish | **Canonical fabricated radiator revision; delivered, operator-unverified** |

## Archive policy

Superseded writeups are in [archive](archive/README.md), labelled historical. Their original revision-specific CAD, render and analysis paths remain available for traceability and script dependencies. Unversioned legacy manifold outputs are G, not the current design. See [output guide](../output/README.md).

Git preserves all earlier revisions, recaps and README/AGENTS history. Retrieve a snapshot into a separate directory with `git archive <tag-or-commit>` when needed; do not replace the current files to inspect history. Older descriptions saying “current”, “selected” or “next” apply only to their labelled snapshot.

## StarTech25U context update —15 September2026

The composite now uses the manufacturer-informed4POSTRACK25U at minimum22in mounting depth, reserves lowerU1 for radiator plumbing and uses Q/R7. Front PVC routes use the accepted shortened free-XYZ rod/contact solution; infrastructure retains geometric65 mm bends. See [current context](context-25U.md). This is an installation iteration, not a new custom-part revision.

## 16 September steel tolerance revisions

- **Q-M02 faceplate:** all cut sizes and X/Z coordinates ±0.10; standard grinding/deburring, no dimensioned face-edge break. Q-M04 body unchanged.
- **R6-M03 radiator:** all cut sizes, profile radii and X/Y coordinates ±0.10; separate flatness and edge finishes unchanged.
- STEP/DXF geometry byte-identical to previous revisions. Original submitted archives preserved; current local index selects the two new revisions.

## R5 outside-corner revisions — 16 September 2026

- **Q-M03 faceplate:** four square outside corners become R5; Q-M04 POM and every cut opening/position are unchanged. Nominal mass 0.394607 kg.
- **R7 / R7-M01 radiator:** four outside corners increase R2 → R5; all fan/radiator holes, rack slots, R50 apertures and 10 ×2 notch are unchanged. Nominal mass 1.247067 kg.
- Both preserve the held ±0.10 mm cut-size/coordinate specifications, raw finish and separate edge treatments. Fresh STEP/DXF/PDF, eleven Q inspection views, four studio views, seven radiator views and nine rack views replace current presentation outputs. No supplier upload.

## Q-M04 body — 16 September 2026

Twelve main-slab outside edges gain C0.50 ±0.10 ×45° ±1° chamfers with modelled corner junctions. All functional geometry is retained. Held body revision replaces Q-M01 locally; submitted originals are untouched. Steel remains Q-M03 / R7-M01. Three new body drawing sheets and 25 affected renders refreshed; total current presentation set 32 images.

## Operator acceptance and new-order authority — 16 September 2026

The operator accepted the complete Q-M04/Q-M03/R7-M01 set on 16 September 2026 and authorised a **separate new JLC order**, superseding the earlier hold. Reuse prior material, finish and goods metadata; compare shipping services and obtain operator confirmation of the cheapest option before final submission. Preserve the original orders and archives. [New-order preparation record](jlc-order-2026-09-16.md).

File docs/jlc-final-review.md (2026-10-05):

# Three-part JLC review: Q-M04 body, Q-M03 faceplate and R7-M01 radiator

Checked against live JLCCNC official pages on **15 September 2026**. Q is operator-approved; the subsequent M4 refinement uses 10 mm full thread, 13 mm pilot. Original R6-M02 specifies raw sheet finish, matching the manifold faceplate. The held Q-M03/R7-M01 revisions add four R5 outside corners to each plate; other cut profiles remain unchanged. The three parts were [submitted for review before payment](jlc-quotation-2026-09-15.md). Subsequent review/acceptance is recorded in [manufacturing status](manufacturing.md). The current Q-M04/Q-M03/R7-M01 set was subsequently submitted as a separate order and approved in the operator’s 17 September screenshot; payment remains pending.

| Part | Process / material selection | Finish and options | Supplier pack |
|---|---|---|---|
| RM10-Q-M04-BODY | CNC milling/drilling/tapping; black unfilled POM, declared POM-C or POM-H stock | As-machined; no polish/coating. Threads YES. 28 G1/4 +12 M4. External deburr only; flush loose chips. | Matching STEP +3-sheet PDF |
| RM10-Q-M03-FACEPLATE | Sheet-metal / flat laser-cut 2 mm SUS304, with hole finishing if needed | Raw stainless sheet finish on BOTH broad faces; no brushing or polishing. Plain through holes; flat profile. | Matching STEP +DXF +2-sheet PDF |
| SN1260-R7-M01-PLATE | Sheet-metal / flat laser-cut 2 mm SUS304, with hole finishing if needed | Same raw sheet finish on BOTH broad faces; no brushing or polishing. 68 plain fixing positions, four air apertures, 10×2 rounded cable notch. Plain through holes; flat profile. | Matching STEP +DXF +3-sheet PDF |

## Official requirements and their application

**Steel finish:** The operator selected raw stainless sheet finish for BOTH plates during quotation preparation, with no brushing or polishing. Q-M03 uses the accepted standard grinding/deburring; R7-M01 retains its specified edge breaks and cable-contact edge rounding. The live [sheet-metal quote form](https://jlccnc.com/sheet-metal-quote) lists a 1000×360 mm brushing limit, smaller than the radiator plate in its short dimension; brushing is therefore no longer requested. No grain direction is specified for raw sheet.

**POM:** JLC lists POM machining, but its generic article mixes POM-C terminology with homopolymer and injection-moulding discussion. It does not identify an offered black stock grade. Thus availability of POM is confirmed; **black unfilled stock, exact family/grade, 410×87×43 envelope stock and datasheet still need confirmation**. No Delrin brand requirement. As-machined exterior and the specified seal-land finishing are requested, not plastic polishing or chemical treatment. [JLC POM material page](https://jlccnc.com/help/article/pom-cnc-machining).

**CNC files and precedence:** STEP/STP is mandatory; JLC recommends matching-name 2D drawings. Geometry normally follows 3D, while threads, tolerances and roughness follow 2D; conflicting website selections override drawings. Accordingly each ZIP has one single-solid STEP with its same-name PDF, and upload options must match the table. The POM STEP deliberately represents tap pilots, as JLC recommends; finished thread type, pitch, depth and gauges are on the PDF. Specific limits require explicit selection and confirmation. [JLC ordering guidelines](https://jlccnc.com/help/article/cnc-machining-ordering-guidelines).

**CNC geometry and threads:** The POM body fits the published CNC envelope. Two Ø11.8 galleries through 410 mm require special deep-drilling review: one-sided ratio 34.75D; opposed nominal 207 mm reach is 17.54D. We have not found an official blanket acceptance for that drilling ratio and do not apply an end-milling cavity rule as a drill acceptance rule. The revised M4 full thread is 2.5× nominal diameter with 2.45 mm full-diameter run-out allowance after the entry/thread; it meets JLC's suggested ≤3D effective thread and ≥0.5D bottom allowance. G1/4 thread + run-out limits are separately specified for front/end and rear ports. [JLC design guideline](https://jlccnc.com/help/article/cnc-machining-design-guideline), [JLC threaded-hole guideline](https://jlccnc.com/help/article/threaded-hole-guideline).

**Steel stock and route:** JLC lists SUS304 sheet at 2 mm and an 800 mm maximum length. Both plates fit this route. Use sheet-metal ordering, rather than assuming their CNC flat-metal minimum of 3 mm admits a 2 mm plate. [JLC sheet materials](https://jlccnc.com/help/article/materials-supported-in-sheet-metal-fabrication), [JLC CNC size limits](https://jlccnc.com/).

**Sheet geometry/files:** JLC requires STEP; same-name PDF/DXF can accompany it in a ZIP. The guide lists 100 MB per file and up to 20 drawings per upload. Its hole minimum is max(1 mm, half thickness), and minimum hole-to-hole distance is 1 mm. Our smallest round holes are 4.5 mm in the manifold plate and 3.6 mm in R7. Both retain webs above that spacing. The manifold's optional outer rack slots retain a 1.90 mm edge ligament; the radiator's is 2.85 mm. Current steel revisions use bilateral ±0.10 mm cut sizes and coordinates. Free-state flatness (0.30 manifold /0.50 radiator) is separate from JLC’s published cutting tolerance. Both parts are flat profiles. [JLC sheet-metal guide](https://jlccnc.com/help/article/sheet-metal-fabrication-guidelines).

## Final checks and open supplier questions

1. **POM drilling:** accept continuous 410 mm galleries, ≤0.30 mm axis deviation/meeting step, no blind webs and no wall breakthrough? Identify the method and any proposed changes.
2. **Material/finish:** confirm black unfilled stock grade, functional seal Ra≤1.6 µm/flatness0.05, other finishes and cleaning. No internal cross-hole deburring operation; external deburr only.
3. **Threads:** confirm G1/4 ISO228-1 tooling/gauging (not tapered threads), full8 after1 entry, and M4×0.7-6H full10 after0.55 entry in13 mm full-diameter pilots. No inserts or arbitrary substitute tapping.
4. **Mating dimensions:** Q-M04 body M4 centres remain ±0.05; Q-M03 plate centres and hole sizes use ±0.10. The accepted capability gives a conservative worst-case M4 radial margin of −0.0121 mm; it is not a guaranteed-interchangeability claim or an outstanding approval gate. See [fit assessment](Q-faceplate-as-drawn-capability.md). Ø32 ±0.10 windows retain approximately 0.517 mm worst-case boss-root clearance. Boss projection remains 0.85–1.15 mm size-only.
5. **Steel:** confirm sheet grade/thickness, hole sizes/positions, free-state flatness, raw sheet finish on both faces and external edge finishing. The cable-notch outline R0.5 is in STEP/DXF; R0.3-0.5 face-edge finishing is additional and must be performed after cutting.
6. **Part inspection:** inspect all finished thread types and depths, pilot depths, bore continuity and separation, seal lands, datum dimensions, hole sizes/coordinates, flatness, edge finish against each part's drawing.

Assembly and operational qualification are separate from this fabrication review: see [Q assembly](assembly-Q.md), [radiator assembly](radiator-rack-plate.md) and [retention engineering](Q-torque-and-creep.md).
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

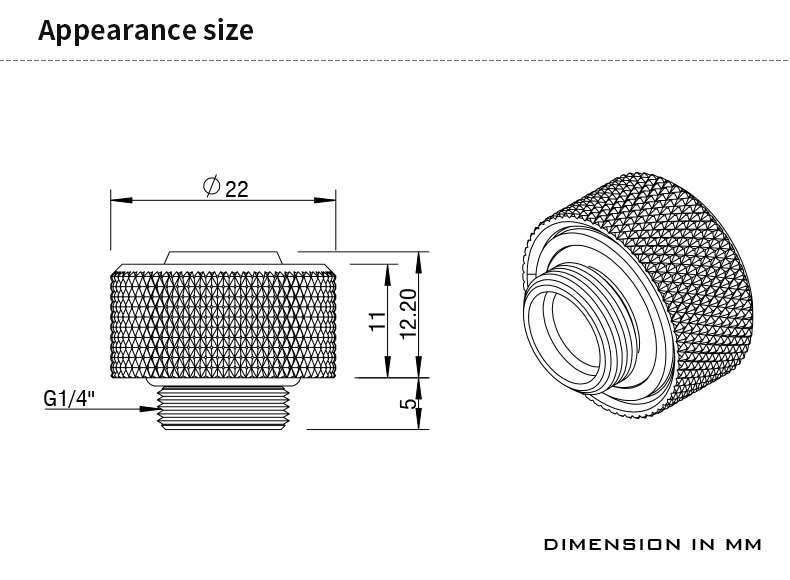
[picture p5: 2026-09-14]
docs/references/barrow-10-16-user-drawing.png

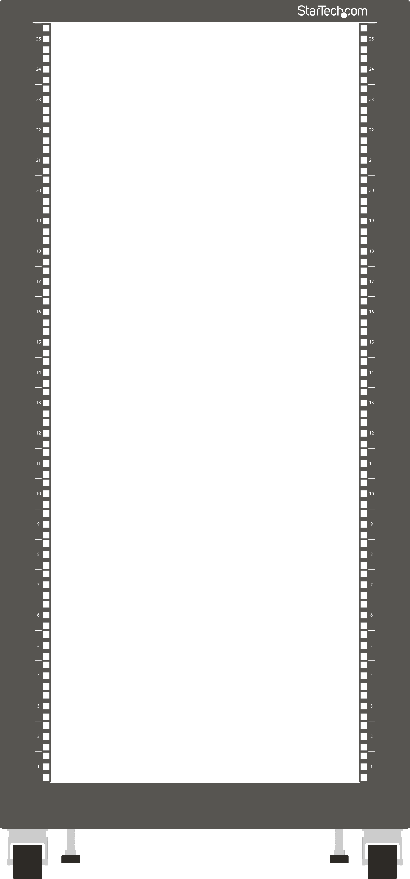
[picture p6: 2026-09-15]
docs/references/startech-25u/stencil-front.png

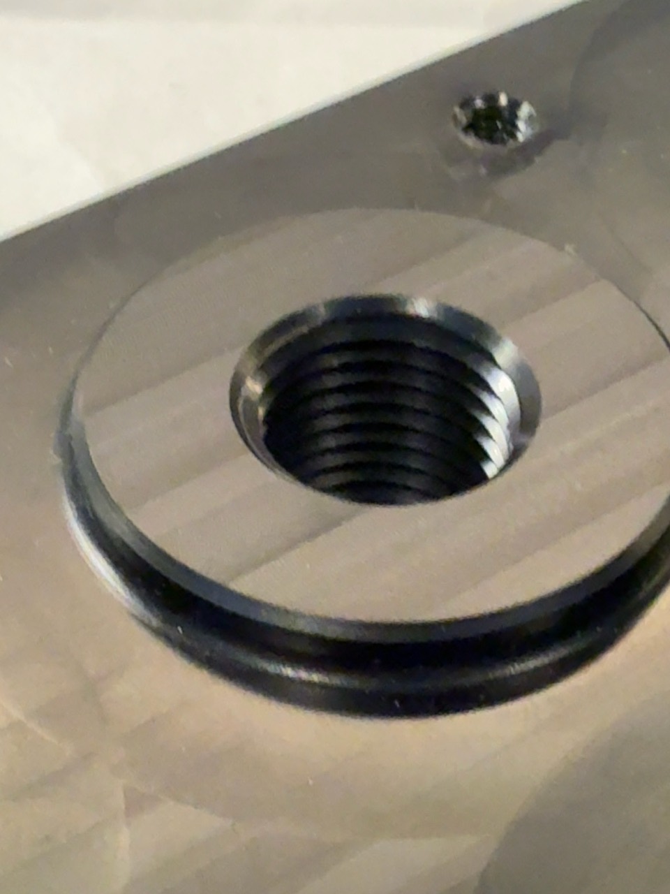
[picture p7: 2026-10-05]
docs/references/first-article-2026-10-05/02-boss-detail.jpg

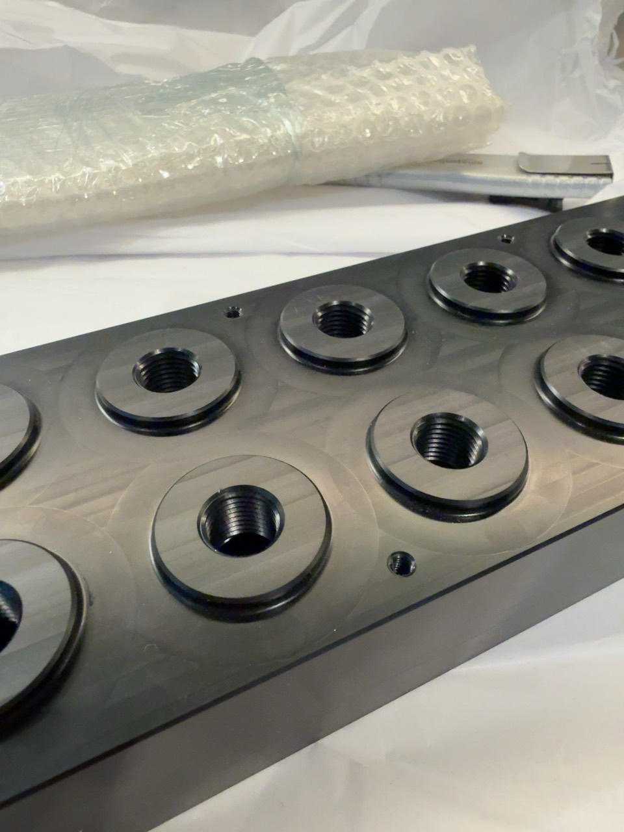
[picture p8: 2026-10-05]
docs/references/first-article-2026-10-05/03-front-pom.jpg

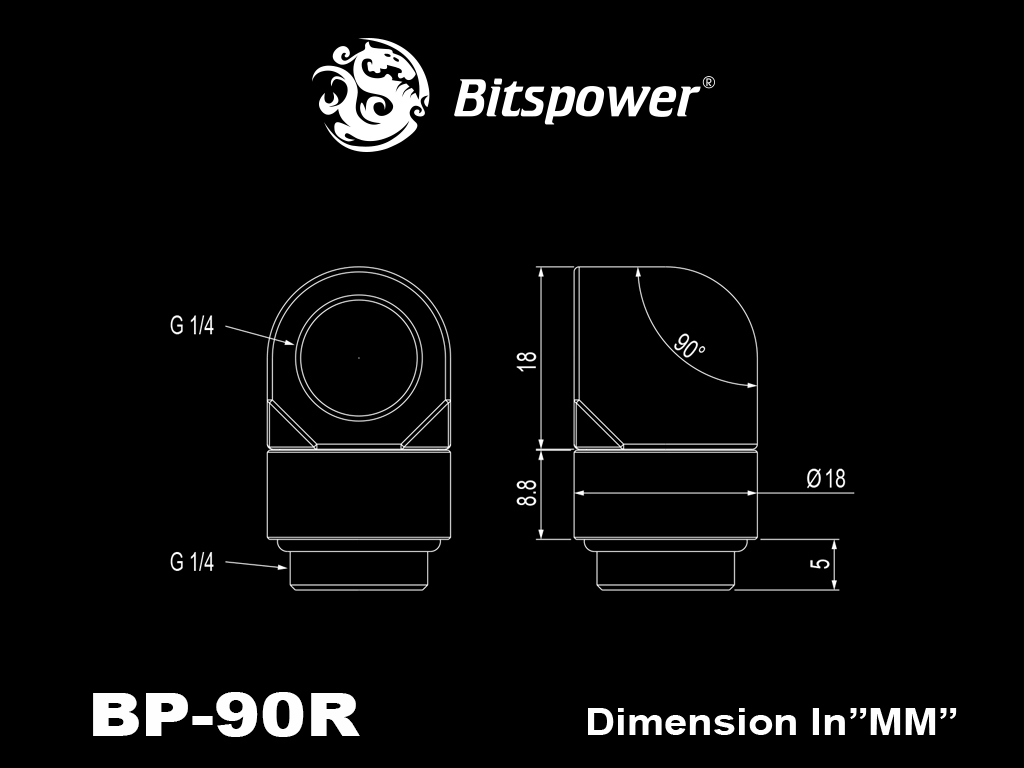
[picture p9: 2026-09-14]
docs/references/bitspower-bp90r-user-drawing.png

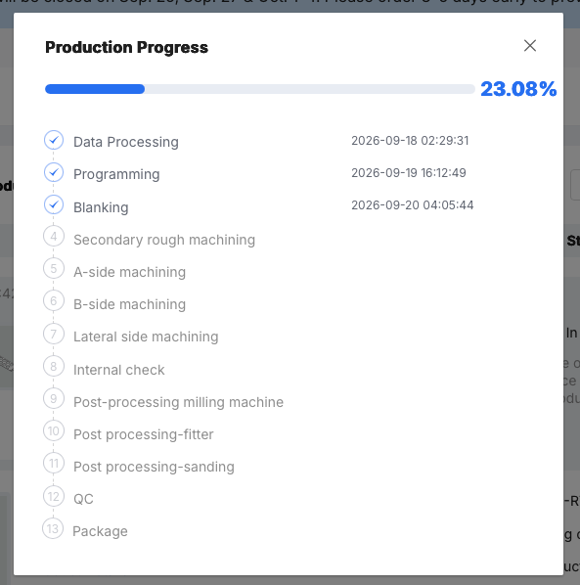
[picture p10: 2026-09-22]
docs/references/jlc/2026-09-22-pom-production.png

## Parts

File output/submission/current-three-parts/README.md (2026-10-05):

# Current three-part fabrication pack

**Canonical delivered revisions: Q-M04 body, Q-M03 faceplate and R7-M01 radiator.** To reproduce the order, download the three ZIPs below and follow [the JLC order guide](../../../docs/order-from-jlc.md). These are byte-identical copies of the revision-specific bundles. [The canonical manifest](../../../cad/current-release.json) selects their paths and hashes. Older outputs remain historical unless explicitly identified as shared dependencies. This index verifies files; it does not submit or pay for an order.

| Part | Fabrication bundle | Process |
|---|---|---|
| Q POM body | [RM10-Q-M04-BODY.zip](RM10-Q-M04-BODY.zip) | CNC milling, drilling and tapping; black unfilled declared POM-C or POM-H |
| Q faceplate | [RM10-Q-M03-FACEPLATE.zip](RM10-Q-M03-FACEPLATE.zip) | 2 mm 304 flat sheet; plain holes and raw sheet finish on both faces |
| R7 radiator plate | [SN1260-R7-M01-PLATE.zip](SN1260-R7-M01-PLATE.zip) | 2 mm 304 flat sheet; plain holes and raw sheet finish on both faces |

Each ZIP contains a same-name single-part STEP and PDF; the steel parts also have a DXF cut profile. The drawings define finished geometry, threads, tolerances, surface finish and inspection. STEP thread cylinders represent tapping pilots. There are eight drawing sheets across the three parts. Both steel drawings specify four R5 outside corners and ±0.10 mm cut dimensions and coordinates. Other cut profiles and fixing positions are retained. Separate flatness limits remain 0.30/0.50 mm; faceplate uses standard deburring, radiator retains its specified cable-contact edge finish.

[Verification](verification.json) records bundle integrity and consistency with the reviewed Q/R7 outputs. [Checksums](SHA256SUMS.txt) cover the index files. Operator manifold fit checks passed; the delivered radiator is operator-unverified. The [JLCCNC first-article report](../../../docs/jlc-first-article.md) records that supplier’s steel-edge sharpness finding. Repeating these ZIPs does not add an improved finishing specification.

[Manifold assembly instructions](../../../docs/assembly-Q.md), [radiator assembly instructions](../../../docs/radiator-rack-plate.md) and engineering assessments are separate project documents, outside these fabrication ZIPs. The current [product views](../../../docs/product-views.md) and [rack scene](../../../docs/context-25U.md) are review references.

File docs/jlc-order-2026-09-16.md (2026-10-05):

# New JLC order — 16 September 2026

The operator accepted Q-M04, including its eight corner flats, and authorised a separate order for one each of the three current parts. The previous hold is superseded. Original Q-M01/R6-M02 fabrication archives remain unchanged; the operator subsequently reported clearing that old order.

Status: **Q-M04 body and Q-M03 faceplate received; operator dimensional and fit checks passed**, reported on 5 October. The radiator plate is also delivered but operator-unverified, pending access to a spare Supernova. The 17 September approval timeline is retained below. Submitted for file review on 16 September 2026 at approximately 15:20 UTC, after the operator explicitly confirmed UPS. JLC displayed “Your order has been submitted.” Review Before Payment was selected. No payment was made or automatic payment authorised. Authentication uses Google OAuth.

| Part | Route | Material / finish | Quantity |
|---|---|---|---|
| RM10-Q-M04-BODY | CNC machining; threads present | POM (Black), unfilled POM-C or POM-H declared per PDF; no surface finish | 1 |
| RM10-Q-M03-FACEPLATE | Sheet metal; no threads | Stainless Steel 304; no surface finish, raw both faces | 1 |
| SN1260-R7-M01-PLATE | Sheet metal; no threads | Stainless Steel 304; no surface finish, raw both faces | 1 |

Reuse the prior saved delivery metadata and goods descriptions: plastic coolant manifold for the body; rectangular stainless plate, HS 732690, for both steel parts. Body tolerance selection remains ±0.05 mm with the part-specific drawing; both steel drawings specify ±0.10 mm. Use the current revision-specific remarks. Upload the body drawing to the additional tolerance-drawing control when offered.

All 32 current presentations already incorporate the accepted geometry: twelve Q product views, four Q studio views, seven R7 radiator views and nine StarTech25U context views. Source hashes, three new body drawing sheets and five inherited steel sheets are checked by the current pack verifier. Accepted tube routes and official fitting geometry are retained.

The new-order [machine-readable record](../output/submission/jlc-order-2026-09-16.json) tracks UI progress; [original quotation history](jlc-quotation-2026-09-15.md) is preserved separately. All three new revisions are approved in the 17 September screenshot below.

## Checkout comparison

| Service | Shipping (USD) | Transit estimate | Terms |
|---|---:|---|---|
| **UPS Worldwide Express Saver — selected** | **71.99** | **3–5 business days** | CPT |
| FedEx Express | 76.33 | 4–7 business days | CPT |
| DHL Express | 122.79 | 2–4 business days | CPT |
| DHL Express (DDP) | 125.12 | 2–4 business days | Additional $66.80 duties/taxes shown |

All four offered priced services were selected in turn to read the checkout charge. An own-freight-account option had no supplier price and was not selected. UPS is the cheapest quoted shipping, saving $50.80 against DHL. CPT excludes destination duties, tax and carrier clearance handling fees.

Pre-review prices: body $128.12, faceplate $9.86, radiator $29.82; merchandise $167.80. UPS checkout total **$239.79**, before destination charges. Estimates remain subject to supplier file review. Current cart references: CNC2609165007659-6347288A (body), SMS2609163002842-6347288A (faceplate), SMS2609163002832-6347288A (radiator). These identifiers exist before final order submission.

The three verified ZIPs were uploaded via the correct CNC/sheet-metal routes. The body PDF was additionally attached at the tolerance-drawing control. The steel UI exposes the extracted STEP names; it does not separately confirm receipt of each ZIP member. Uploaded bundles contain matching STEP/PDF and, for steel, DXF. The remarks fields required compact notes; exact entered wording is in the JSON record.

## Historical POM price comparison and portal check — 16 September

The new batch is **W2026091623209243**. The 16 September portal check showed Q-M04 as **Reviewing**, $128.12, six-day build. Its product details confirm POM(Black), no finish, ±0.05 mm tightest tolerance, Standard appearance, threads Yes, quantity1, 410×87×43 mm and1326122.41 mm³. No material/tolerance/thread downgrade was found.

| POM price stage | Original Q-M01 | New Q-M04 |
|---|---:|---:|
| Automatic estimate before review | $128.74 | $128.12 |
| After supplier review | $197.26; Approved; 8 days | Not yet available; Reviewing; 6 days |

The large apparent reduction compares different review stages. Like-for-like automatic estimates differ by only $0.62 (about0.48%). JLC has not explained that small difference; do not attribute it to the chamfers or a particular quotation algorithm without evidence. Q-M04 adds the twelve perimeter chamfers and eight corner flats, removing267.833 mm³ (about0.0202%); all functional features and thread requirements remain. The new reviewed price may rise again.

The same portal check displayed shipping **$65.81** and total **$233.61**, down from the checkout estimates $71.99/$239.79. This is a later observation, not a change to the operator's approved carrier or a payment. Reason for the shipping recalculation was not displayed.

On 16 September 2026, the operator reported clearing redundant original batch W2026091606463892. This is operator-reported, not independently rechecked in the portal. No further cancellation action is required; retain its fabrication archives as history. At that 16 September check, new batch W2026091623209243 was awaiting approval; the 17 September screenshot supersedes that status. Do not sign out or restart Safari in ways that disrupt the operator's session; sign-in uses Google OAuth.

The operator considers deep-bore setup a likely contributor to the reviewed POM price. This is a plausible explanation, not a supplier-itemised cost breakdown.

## Supplier approval — 17 September 2026

The operator supplied the [JLC order timeline screenshot](references/jlc/2026-09-17-approved.png), reporting approval without comment. Its part references match the three uploaded revisions:

| Part | Supplier reference | Status | Displayed approval time |
|---|---|---|---|
| Q-M04 POM body | CNC2609165007659-6347288A | Approved | 17 September 2026, 06:56:34 |
| Q-M03 manifold faceplate | SMS2609163002842-6347288A | Approved | 17 September 2026, 08:08:51 |
| R7-M01 radiator plate | SMS2609163002832-6347288A | Approved | Approval timestamp not visible in the crop |

The batch timeline states “All orders have been reviewed, waiting for payment now.” at 08:08:51 on 17 September. Times are transcribed as displayed; the portal timezone is not established. No review comments or requested changes appear in the crop. This is evidence of supplier file-review approval of the current three revisions, rather than a live portal recheck. Final reviewed prices, selected POM grade and actual machining route are not shown. Previous prices remain historical observations; do not infer that the automatic POM estimate is the final price. No payment has been authorised or made by the agent. Fabrication bundles are unchanged.

## Production update — 22 September 2026

Source: operator-supplied [part status screenshot](references/jlc/2026-09-22-parts-status.png) and [POM production timeline](references/jlc/2026-09-22-pom-production.png). No live portal check was made.

| Current part | Displayed status | Displayed price (USD) | Displayed build time |
|---|---|---:|---|
| Q-M04 POM body | Approved; production progress 23.08% | 197.26 | 8 days |
| Q-M03 manifold faceplate | Awaiting carrier pickup | 9.86 | 2 days |
| R7-M01 radiator plate | Awaiting carrier pickup | 29.82 | 2 days |

The POM now has exactly the same US$197.26 price and eight-day build time as the original manually reviewed Q-M01 quotation. The apparent discount in the earlier automatic estimate did not survive review. The price rose US$69.14 from US$128.12. The three displayed part prices sum to US$236.94, excluding shipping and destination charges. Current shipping and final order total are not visible; do not substitute the historical shipping charge as a confirmed current amount. Build time is the displayed quotation field, not a countdown from this screenshot.

| POM stage | Screenshot status / displayed completion time |
|---|---|
| Data Processing | Complete — 18 September 2026, 02:29:31 |
| Programming | Complete — 19 September 2026, 16:12:49 |
| Blanking | Complete — 20 September 2026, 04:05:44 |
| Secondary rough machining | Not marked complete |
| A-side machining | Not marked complete |
| B-side machining | Not marked complete |
| Lateral side machining | Not marked complete |
| Internal check | Not marked complete |
| Post-processing milling machine | Not marked complete |
| Post processing-fitter | Not marked complete |
| Post processing-sanding | Not marked complete |
| QC | Not marked complete |
| Package | Not marked complete |

Times are transcribed as displayed; the portal timezone is unknown. 3/13 ×100 = 23.0769%, consistent with a stage-count progress indicator, not measured cutting time or remaining lead time. Incomplete markers do not establish whether a stage has started or whether updates are immediate.

Engineering interpretation: blanking normally denotes preparing the stock blank. A-side/B-side/lateral-side machining is consistent with our assessment of multiple face orientations. These broad workflow labels do not identify which face is A, where the galleries are drilled, the fixture arrangement, drill direction, or machine axis count. Post-processing labels may be generic supplier workflow stages; they do not independently establish additional polishing, sanding of seal lands or internal deburring beyond the submitted requirements. No change to the accepted finish or deburring scope is inferred.

The metal parts have finished production according to the operator and are awaiting carrier pickup in the portal. They are not shown as dispatched; combined or separate shipment is not established. The POM remains in the production workflow. Payment details/date are not shown, and the agent has made no payment. Fabrication packages are unchanged.

## First-article observations — 5 October 2026

The operator supplied photographs of the received manifold body, the faceplate positioned over its bosses, a fitted QD3 and the POM corner detail. The operator subsequently confirmed: “So far, I can verify that the manifold and plate are dimensionally correct, and all M4 screw holes are correct on the POM, and the G1/4 ports are correct.” This verification applies to the received Q-M04 body and Q-M03 manifold faceplate.

| Feature / observation | Operator finding |
|---|---|
| Manifold and faceplate dimensions | Correct |
| All POM M4 screw holes | Correct |
| G1/4 ports | Correct |
| QD3 thread engagement | Smooth |
| POM corner detail | Good / accepted |
| Holding marks | Accepted as a cosmetic detail where concealed by the faceplate |
| 2 mm steel faceplate | Chosen thickness confirmed suitable; mounts without perceptible flex |

These are first-hand operator dimensional/fit observations and acceptance of the POM corner detail and concealed holding marks. Steel-edge finish has a separate open finding below. No numerical measurement sheet or gauge results were supplied, so the record does not invent measured values, certified thread classes or universal interchangeability. No leak-test result has yet been reported. The dimensional verification is retained as accepted evidence and does not need to be reopened without a relevant finding.

The operator subsequently confirmed that the radiator plate is delivered but operator-unverified: no spare Supernova is currently available for fit checks. No geometry, manufacturing instructions or submitted fabrication bundles change as a result of these observations.

Archived operator photographs:

- [01-assembled-qd3](references/first-article-2026-10-05/01-assembled-qd3.jpg)
- [02-boss-detail](references/first-article-2026-10-05/02-boss-detail.jpg)
- [03-front-pom](references/first-article-2026-10-05/03-front-pom.jpg)
- [04-rear-pom](references/first-article-2026-10-05/04-rear-pom.jpg)
- [05-corner-detail](references/first-article-2026-10-05/05-corner-detail.jpg)

### Delivery clarification and steel-finish finding

The operator elects to leave R7-M01 as delivered and operator-unverified until a spare Supernova is available. Receipt is confirmed; radiator fit, hole alignment and assembled behaviour have not been checked.

The operator reports that JLC left holding marks on the POM. These are acceptable where hidden by the stainless faceplate. The plate draws the eye and establishes the assembly's perceived quality, making the quality and consistency of its visible finish important. This is a quality-control requirement for future evaluation, not an instruction to change the selected matching raw stainless finish.

There is slight sharpness on the steel. Record this as an open tactile edge-finish finding: standard deburring as delivered may be inadequate for the intended handling quality. The exact edges, severity and cause have not been characterised, and the finding does not by itself prove a JLC process defect or breach of the accepted faceplate deburring concession. It does not imply that R7-M01's separate cable-contact edge-round requirements were waived.

For repeat production, resolve an achievable, inspectable edge-finish acceptance with the supplier based on the physical sample, and control visible plate blemishes and finish consistency. No chamfer size, additional finishing process or corrective rework is selected by this observation. Current drawings/ZIPs and dimensional acceptance remain unchanged; no supplier contact or new order is authorised by this record.

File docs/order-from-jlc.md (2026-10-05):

# Order the current three parts from JLC

This guide reproduces the **Q-M04 body, Q-M03 faceplate and R7-M01 radiator plate** fabricated for this project. Use one of each unless you deliberately want another quantity. You do not need to run the generators or obtain the historical project revisions.

For changed designs, first follow [the new-revision workflow](new-revision.md). Its generated release README supplies the new ZIPs and per-part metadata; the upload/account/shipping process below still applies.

## Download exactly these bundles

| Part | Download | JLC category | Material | Finish | Threads |
|---|---|---|---|---|---|
| Manifold body | [RM10-Q-M04-BODY.zip](../output/submission/current-three-parts/RM10-Q-M04-BODY.zip) | CNC machining | POM (Black); unfilled POM-C or POM-H declared per drawing | No surface finish | Yes: 28 G1/4 + 12 M4 |
| Manifold faceplate | [RM10-Q-M03-FACEPLATE.zip](../output/submission/current-three-parts/RM10-Q-M03-FACEPLATE.zip) | Sheet Metal | Stainless Steel 304 | No surface finish; raw both faces | No |
| Radiator plate | [SN1260-R7-M01-PLATE.zip](../output/submission/current-three-parts/SN1260-R7-M01-PLATE.zip) | Sheet Metal | Stainless Steel 304 | No surface finish; raw both faces | No |

These direct links select the delivered fabrication revisions, not the original order that was superseded. [Machine-readable selection and hashes](../cad/current-release.json) and [pack checksums](../output/submission/current-three-parts/SHA256SUMS.txt) identify the same files. On GitHub, open each file and use Download raw file; do not save its HTML preview as a ZIP.

## Submit for quotation

1. Start a new JLC quotation. Upload the body under CNC machining and the two plates under Sheet Metal. The original process accepted a separate ZIP per part; if the interface instead requests separate files, extract and attach all members of that part's ZIP.
2. Select the table's materials, finish and quantity. The body was quoted with threads enabled, Standard appearance and ±0.05 mm as the tightest tolerance selector; the attached PDF carries the actual feature-specific requirements. Both steel drawings specify ±0.10 mm cut dimensions/coordinates and separate flatness requirements. Do not mark either steel plate as tapped.
3. Verify that the **matching PDF accompanies every STEP**. Attach the body PDF in the additional tolerance-drawing field when offered. Steel ZIPs also contain matching DXFs. STEP threads are represented by pilot cylinders: manufacturing the STEP as plain bores would not reproduce this part.
4. Use the part remarks below. For goods metadata, the original body description was “Plastic coolant manifold”; steel was “Stainless steel Rectangular Plate”, HS 732690. Confirm the classifications offered for your own order and destination.
5. Choose review before payment where offered. Have JLC assess the actual submitted PDFs, including the two Ø11.8 × 410 mm galleries and external finish requirements. Review any proposed deviation against the specific part drawing.
6. Compare current shipping charges. The historical UPS choice was destination- and date-specific; it is not a reusable shipping quotation. Inspect the reviewed price before paying.

Portal labels and available options may change. This procedure records the successful September 2026 route, not a claim of live UI verification.

## Part remarks

The following are the submitted manufacturing remarks, retained so another user can reproduce the same request. The PDFs remain the detailed fabrication definition.

**Body**

```text
Q-M04 PDF governs.12 edges C0.50+/-0.10 x45deg+/-1deg;8 corner flats per STEP.Declare black unfilled POM-C/H.28 G1/4+12 M4 threads;STEP pilots.External deburr only;flush chips.Confirm D11.8x410 galleries/deviations.
```

**Manifold faceplate**

```text
Q-M03 PDF/DXF govern. Raw 304 both faces; no brushing/polishing. Cut sizes/coordinates +/-0.10mm; four R5 corners; plain holes. Standard grinding/deburring accepted; no complete burr-removal guarantee. Flatness 0.30mm max.
```

**Radiator plate**

```text
R7-M01 PDF/DXF govern. Raw 304 both faces; no brushing/polishing. Cut sizes/coordinates +/-0.10mm; four R5 corners; plain holes. Flatness 0.50mm max. External edge finishing incl cable-contact rounds per PDF.
```

## What this order reproduces

The JLCCNC first article passed the operator's manifold dimensional/thread fit checks. The delivered steel has slight sharpness; its edge-finish adequacy remains an open finding. **Ordering the same pack repeats the existing finish requirement, not a newly improved deburring specification.** The faceplate concession does not waive the radiator's separate cable-contact rounding. If you want a different edge finish, agree and document the changed requirement rather than silently treating it as part of these released files. See [the JLCCNC report](jlc-first-article.md).

The radiator plate is delivered but not yet checked against a spare Supernova. Bought-in fittings, plugs, screws, fans and radiator are excluded from these three custom-part ZIPs. Use the separate [manifold](assembly-Q.md) and [radiator](radiator-rack-plate.md) assembly guides.

September 2026 displayed reviewed part prices were US$197.26 + US$9.86 + US$29.82 = **US$236.94 for one of each**, excluding shipping and destination charges. They are historical comparison data, not a current quote. [The order record](jlc-order-2026-09-16.md) retains the complete chronology.

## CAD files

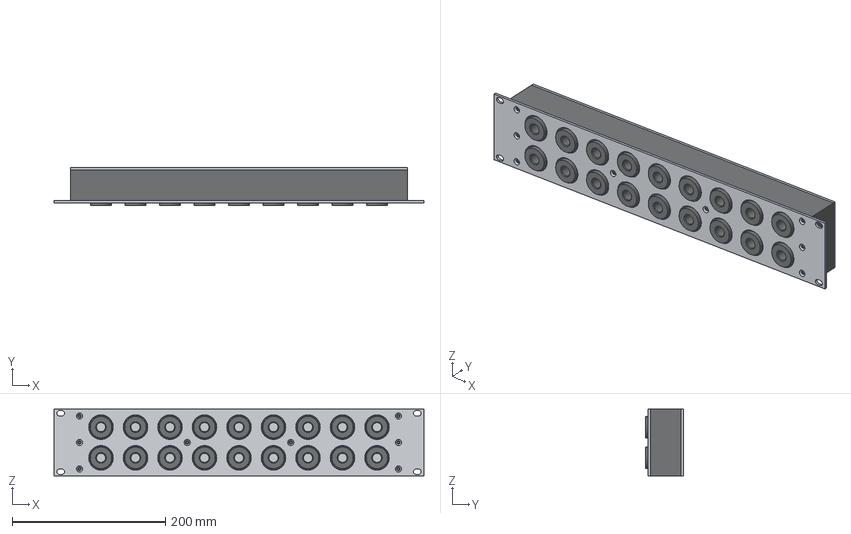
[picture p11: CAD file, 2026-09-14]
output/cad/manifold-assembly.step
482.6 x 49.0 x 87.0 mm
lid
faceplate
seal_1
seal_2

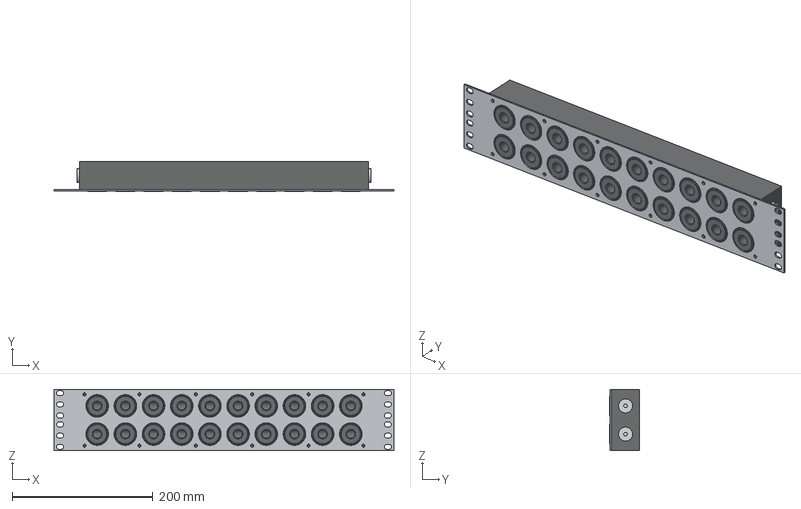
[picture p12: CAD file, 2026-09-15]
output/long-bore-P/cad/manifold-assembly.step
482.6 x 43.0 x 87.0 mm
faceplate
REFERENCE_side_plug_1
REFERENCE_side_plug_2
REFERENCE_side_plug_3
REFERENCE_side_plug_4

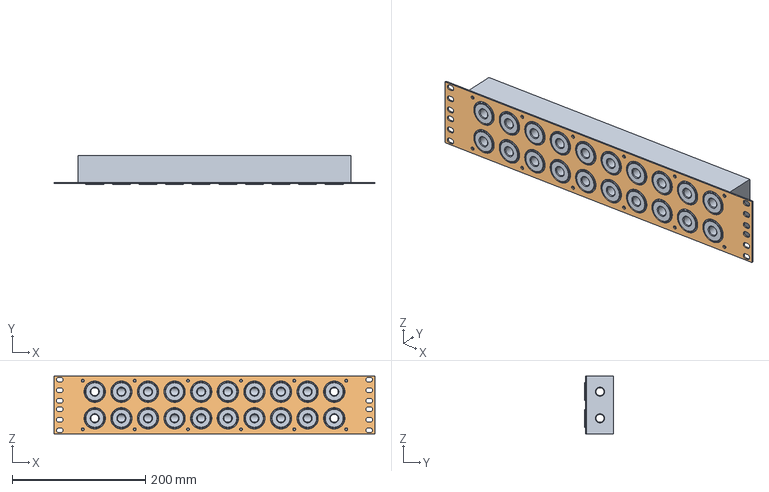
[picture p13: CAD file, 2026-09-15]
output/long-bore-Q/cad/manifold-assembly.step
482.6 x 43.0 x 87.0 mm
POM_Q
unchanged_P_faceplate

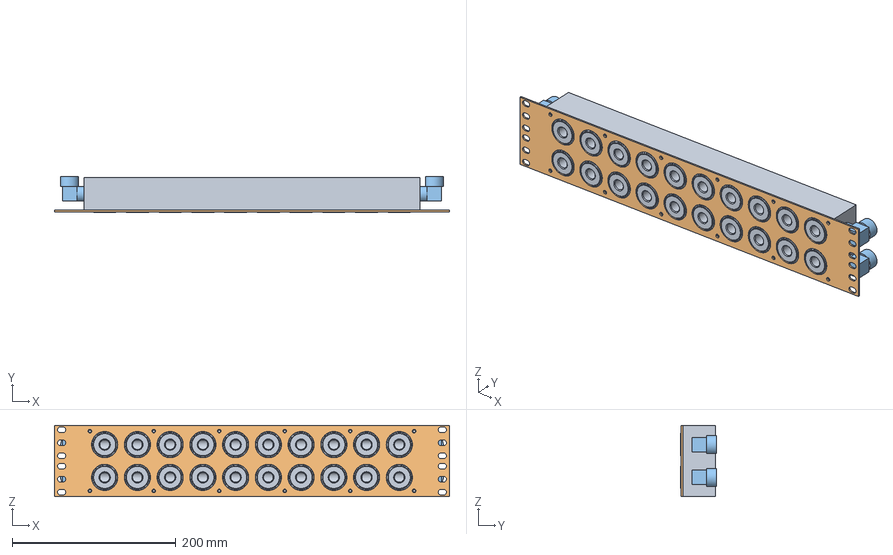
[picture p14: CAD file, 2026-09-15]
output/long-bore-P/cad/elbow-envelope-assembly.step
482.6 x 44.2 x 87.0 mm
faceplate
REFERENCE_fitting_1
REFERENCE_fitting_2
REFERENCE_fitting_3
REFERENCE_fitting_4

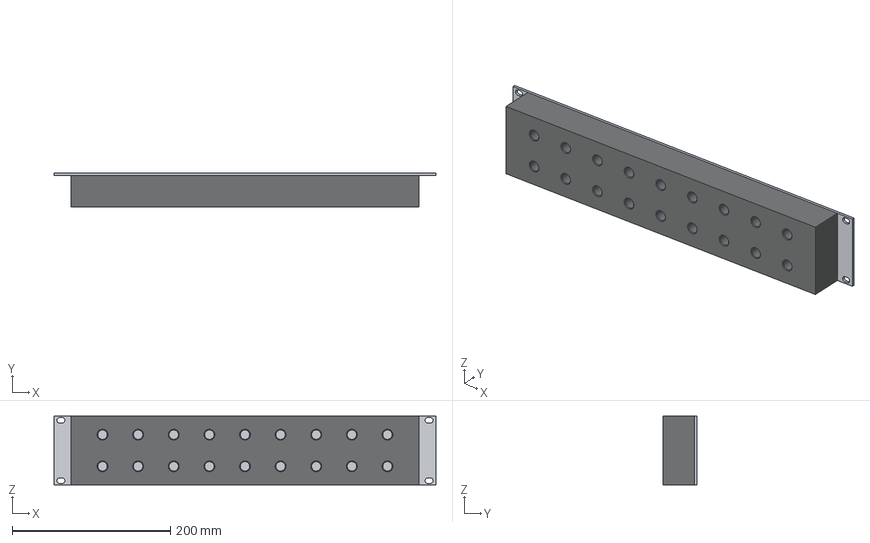
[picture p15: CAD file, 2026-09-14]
output/backplate/cad/manifold-assembly.step
482.6 x 43.0 x 87.0 mm
backplate
seal_1
seal_2

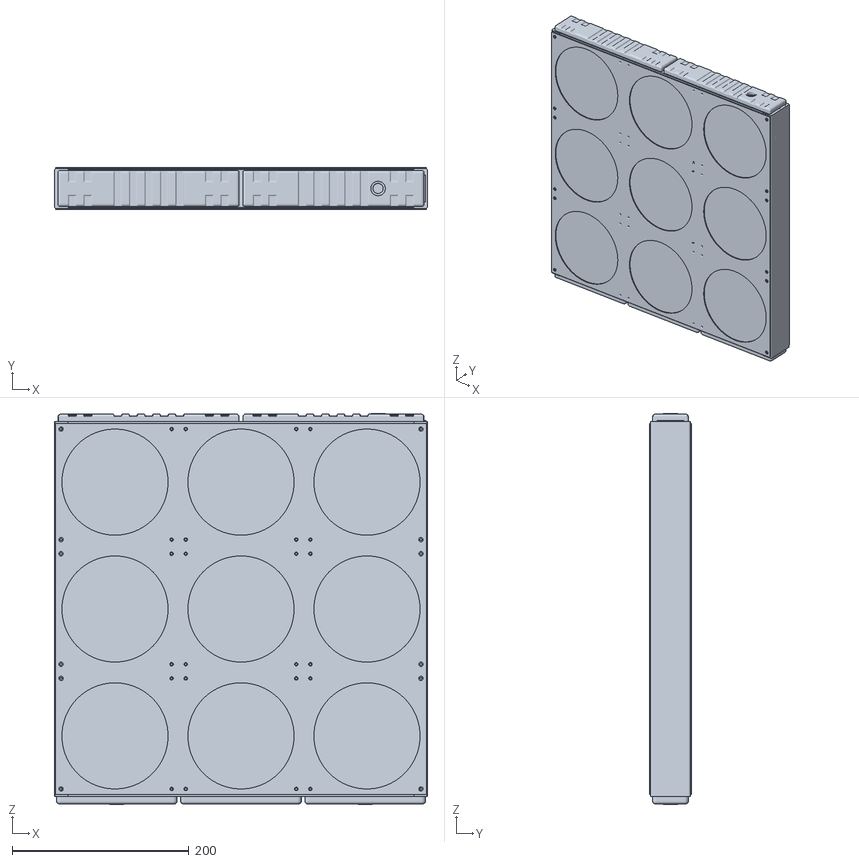
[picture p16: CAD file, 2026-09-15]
docs/references/alphacool-14351-manufacturer.stl
422.0 x 48.0 x 442.2

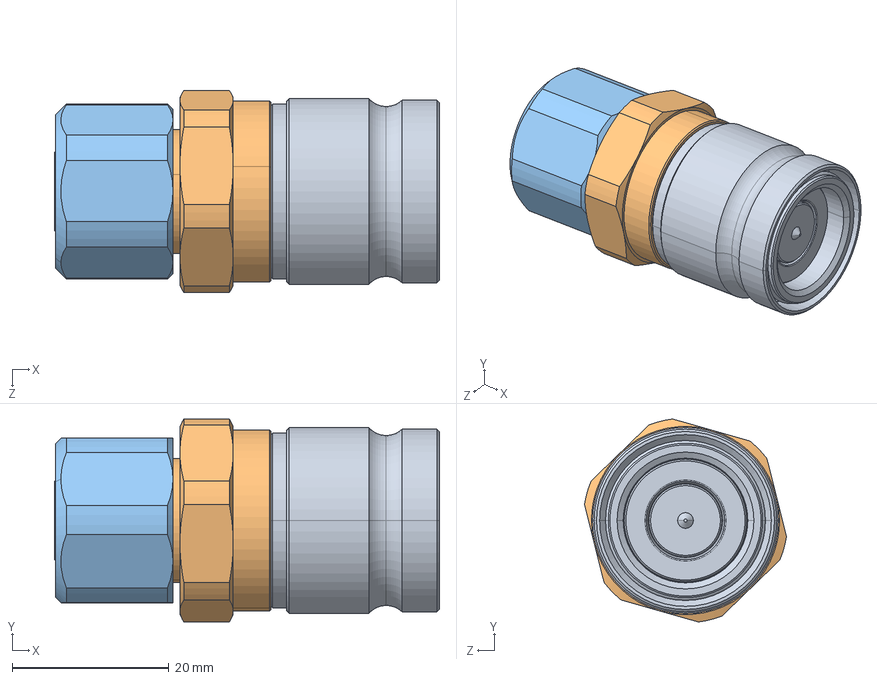
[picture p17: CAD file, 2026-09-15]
docs/references/koolance-qd3/qd3-ft10x13.step
49.1 x 25.9 x 25.8 mm
female body
Compression 10X13, Female 喻闌
Compression 10X13 cap nut

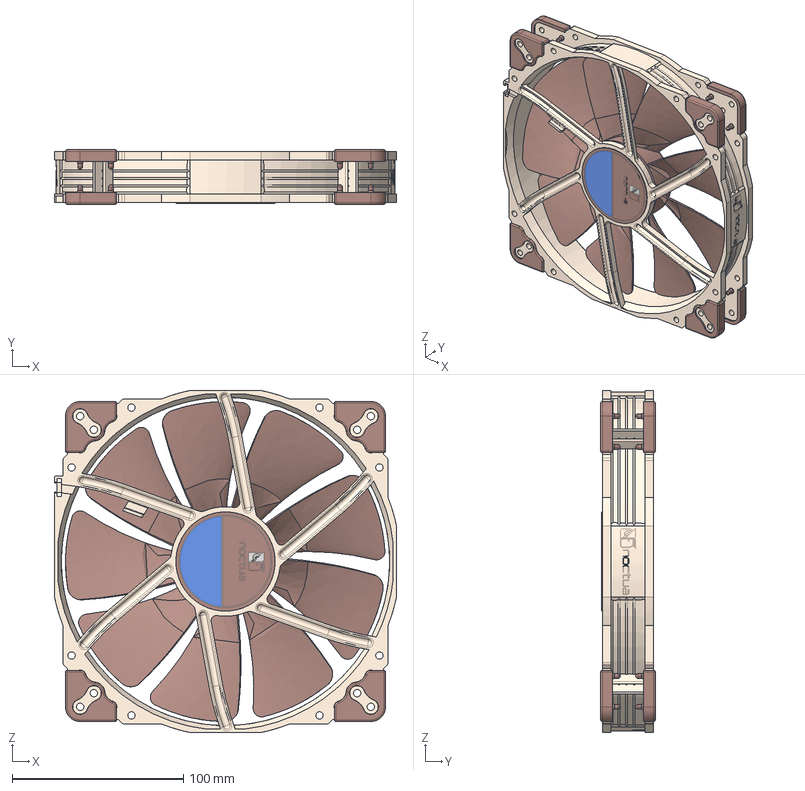
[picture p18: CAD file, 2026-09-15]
docs/references/noctua-nf-a20/NF-A20_Public-CAD.stp
200.0 x 32.0 x 200.0 mm
NF-A20_Frame_Public
NF-A20_Impeller_Public
NA-AVP6 x 8
NF-A20_Lablel-Simple-JPEG

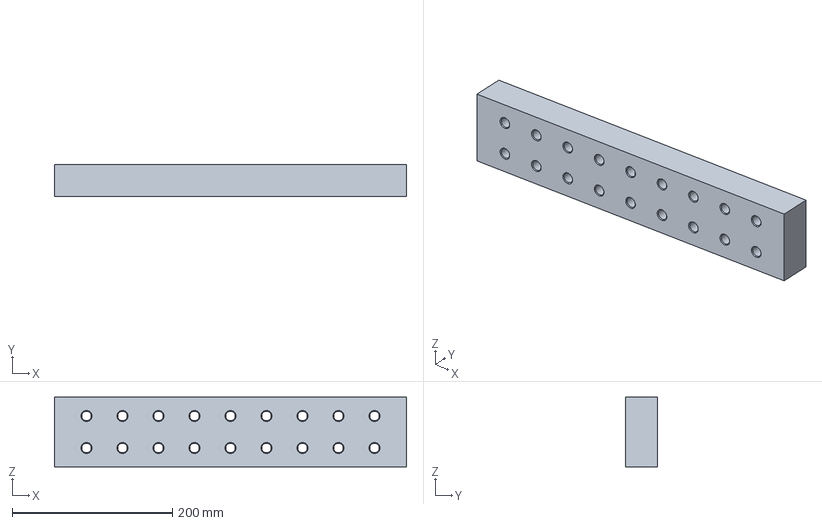
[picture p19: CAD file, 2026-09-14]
output/backplate/cad/body.step
440.0 x 40.0 x 87.0 mm

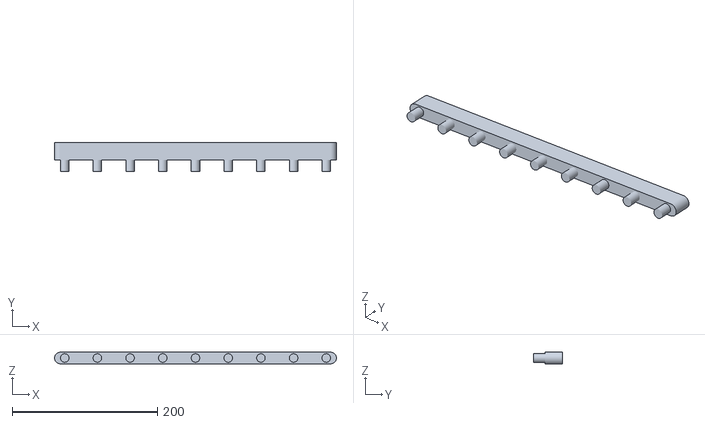
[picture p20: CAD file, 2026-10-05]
output/backplate/meshes/gallery_0.stl
388.0 x 40.0 x 16.0

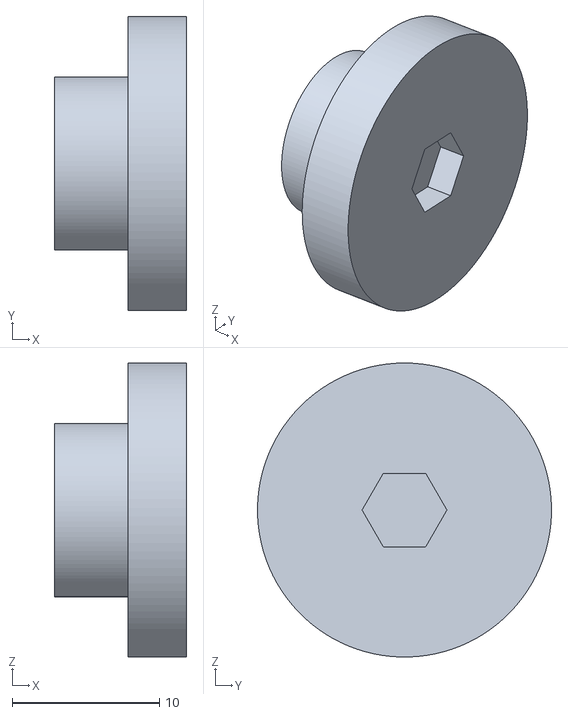
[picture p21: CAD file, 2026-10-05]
output/long-bore-H/meshes/side_plug_1.stl
9.00 x 20.0 x 20.0

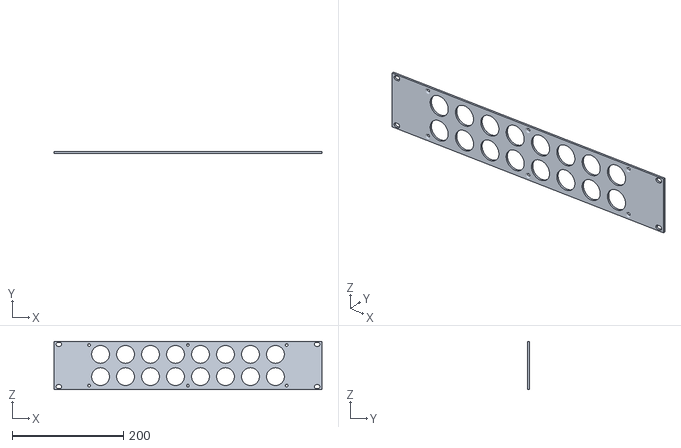
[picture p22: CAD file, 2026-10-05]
output/long-bore-I/meshes/faceplate.stl
482.6 x 3.00 x 87.0

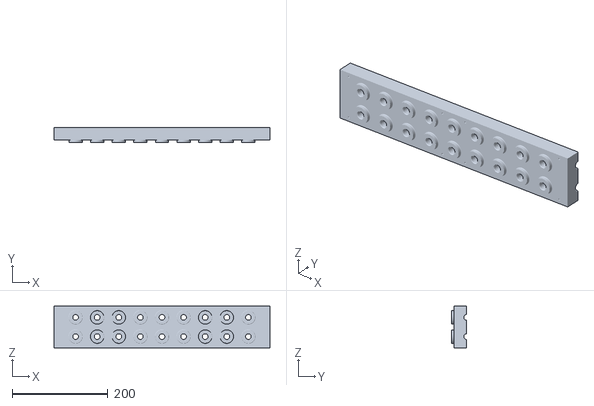
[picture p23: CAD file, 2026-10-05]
output/long-bore-J/meshes/body-section.stl
450.0 x 32.0 x 87.0

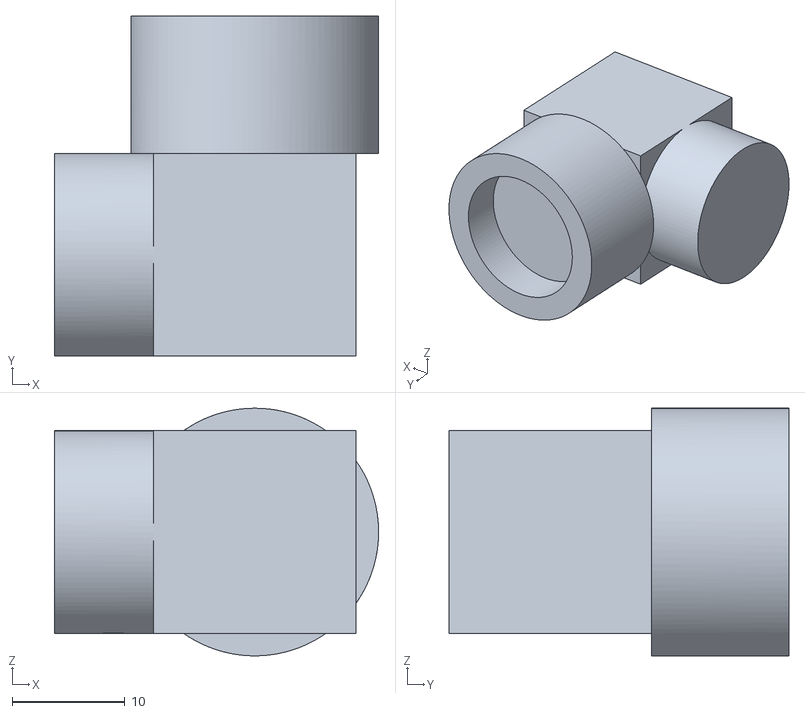
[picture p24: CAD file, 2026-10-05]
output/long-bore-K/meshes/elbow-reference-3.stl
28.8 x 30.2 x 22.0

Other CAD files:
output/long-bore-L/meshes/side_plug_3.stl
output/long-bore-M/meshes/side_plug_3.stl
output/long-bore-N/meshes/elbow-reference-1.stl
output/long-bore-O/meshes/side_plug_3.stl
docs/references/koolance-qd3/qd3-mtg4.step
output/assembly/Q/REFERENCE-M4x10-ISO7380.step
output/assembly/Q/REFERENCE-assembled-with-screws.step
output/backplate/cad/backplate-flat.dxf
output/backplate/cad/backplate.step
output/backplate/manifold-review.blend
output/backplate/meshes/backplate.stl
output/backplate/meshes/body.stl
output/backplate/meshes/gallery_1.stl
output/cad/body.step
output/cad/faceplate.step
output/cad/lid.step
output/cad/rear-cover-flat.dxf
output/context-24U/24U-context.blend
output/long-bore-H/cad/body.step
output/long-bore-H/cad/faceplate-flat.dxf
output/long-bore-H/cad/faceplate.step
output/long-bore-H/cad/fluid-network-1.step
output/long-bore-H/cad/fluid-network-2.step
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

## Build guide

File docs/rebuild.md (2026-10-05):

# Rebuilding current outputs

Use millimetres and explicit revision flags. Several shared/legacy scripts default to G, M, O-M02 or R1; calling them without the commands below can regenerate an older design.

## Environment

The supported authoring environment is **macOS and Python 3.12**, with Blender installed separately. Blender 5.2.1 LTS is the version used for the latest checks. The standard requirements cover CAD, DXF, PDF generation/packaging and the existing tube-equilibrium tools. The drawing programs use macOS Arial fonts; Blender examples use its normal application path. Where a renderer accepts `--device METAL`, omit that option to use its CPU default if needed. Other-platform failures will be investigated when reported; no Linux-specific adaptation has been added pre-emptively.

```sh
python3.12 -m venv .venv
.venv/bin/python -m pip install -r requirements.txt
.venv/bin/python scripts/check_environment.py
.venv/bin/python scripts/check_publication.py
```

`check_environment.py` checks the declared package versions/imports, Arial, Blender startup and small STEP/DXF/PDF round trips. Use `--blender /path/to/Blender` if installed elsewhere. These are tested top-level dependency pins, not a promise of byte-identical exports across every future transitive dependency. The publication check verifies the retained fabrication pack and inputs without regenerating them.

For the optional historical structural-analysis tools:

```sh
.venv/bin/python -m pip install -r requirements-fea.txt
.venv/bin/python scripts/check_environment.py --fea
```

A separate CalculiX 2.23 executable is only needed to solve new structural cases; reading the retained results does not require it. The original solver ran on Linux; this does not change the macOS CAD/Blender baseline.

**To make a new revision, follow [the contributor workflow](new-revision.md).** The commands below reproduce existing revisions into their existing paths. Run them only in a disposable checkout for reproduction checks; do not overwrite released archives in your working branch. For a new revision, copy/adapt the relevant generators to new output paths and use the separate release helper. Ordering existing parts needs none of these installations.

Render meshes and scene descriptions are tracked beside the matching revision under `output/`. The Q inspection renderer reads its two gallery meshes from `output/long-bore-Q/meshes/` and its finished solids from `output/manufacturing/`; no preliminary cache preparation is needed.

For a read-only check of current download selection, hashes and navigation, run:

```sh
.venv/bin/python scripts/check_publication.py
```

## Current steel specification revisions: Q-M03 / R7-M01

Preserve the submitted Q-M01 body and original supplier archives. To rebuild the current R5-corner steel revisions, retaining accepted ±0.10 mm cut tolerances:

```sh
.venv/bin/python scripts/prepare_Q_faceplate_manufacturing_revision.py --manufacturing-revision Q-M03
.venv/bin/python scripts/build_radiator_plate.py --revision R7
.venv/bin/python scripts/prepare_radiator_production.py --manufacturing-revision R7-M01
# Inspect both PDFs (five sheets) before packaging.
.venv/bin/python scripts/draw_Q_production.py --faceplate-manufacturing-revision Q-M03 --faceplate-only
.venv/bin/python scripts/draw_radiator_production.py --manufacturing-revision R7-M01
.venv/bin/python scripts/package_Q_faceplate_manufacturing_revision.py --manufacturing-revision Q-M03
.venv/bin/python scripts/package_radiator_production.py --manufacturing-revision R7-M01
# Render and inspect current presentations below before finalising the index.
```

These commands do not upload. Regenerating an existing revision may change file bytes and invalidate the original source/review hashes even when the nominal design is unchanged. Inspect regenerated drawings and presentations in the disposable checkout; retain the delivered archives and their historical review records in the project. For new revisions, use the new-revision workflow rather than changing those historical hashes.

## Current POM body revision Q-M04

After preparing the Q-M03 faceplate, run:

```sh
.venv/bin/python scripts/prepare_Q_body_manufacturing_revision.py
.venv/bin/python scripts/draw_Q_production.py --body-manufacturing-revision Q-M04 --body-only
# Render and inspect the three new body sheets before packaging.
.venv/bin/python scripts/package_Q_body_manufacturing_revision.py
```

Q-M04 preserves the submitted Q-M01 source and adds only the twelve C0.5 ×45° slab-edge chamfers. It also refreshes the current assembly STEP; run this step after faceplate preparation. Current Q product/studio/context renderers load Q-M04. Do not overwrite submitted archives. The accepted new-order pack is Q-M04 body + Q-M03 faceplate + R7-M01 radiator. Current review comprises three new body sheets, five unchanged steel sheets, 25 refreshed manifold/studio/context images and seven inherited radiator images. The tube equilibrium remains unchanged.

## Original manifold Q / Q-M01 reproduction

Q derives from the retained P solids and source-fitting library. Do not rebuild P just to rebuild Q.

```sh
.venv/bin/python scripts/build_revision_Q.py
.venv/bin/python scripts/prepare_Q_production.py
.venv/bin/python scripts/assess_Q_retention.py
.venv/bin/python scripts/assess_Q_torque.py
.venv/bin/python scripts/draw_revision_Q.py
# Inspect all PDF sheets before packaging:
.venv/bin/python scripts/draw_Q_production.py
.venv/bin/python scripts/package_Q_production.py
/Applications/Blender.app/Contents/MacOS/Blender -b --python scripts/render_revision_Q.py
/Applications/Blender.app/Contents/MacOS/Blender -b --python scripts/render_photoreal_product.py -- --iteration Q --device METAL
```

Original supplier files are Q-M01; current faceplate specification is Q-M03. Do not run the original drawing/package commands to overwrite submitted archives during a steel-only revision. assembly references are separately in `output/assembly/Q/`. O-M02 manufacturing scripts are historical and must not be used for Q. Shared official fitting meshes remain under `output/long-bore-P/koolance-fit/`. The Q renderer shows unchanged button heads representing M4×10, with hidden shanks omitted. No upload occurs.

## Original radiator R6 / R6-M02 reproduction

```sh
.venv/bin/python scripts/build_radiator_plate.py --revision R6
.venv/bin/python scripts/prepare_radiator_production.py --manufacturing-revision R6-M02
# Inspect all three rendered PDF sheets:
.venv/bin/python scripts/draw_radiator_production.py --manufacturing-revision R6-M02
# Package after visual inspection:
.venv/bin/python scripts/package_radiator_production.py --manufacturing-revision R6-M02
/Applications/Blender.app/Contents/MacOS/Blender -b --python scripts/render_radiator_plate.py -- --revision R6 --plate-only --device METAL
```

For a populated radiator assembly, first run `prepare_radiator_fan_mounts.py` with the CAD environment, then render R6 without `--plate-only`. The checked-in R6 images are the bare plate and notch views; populated R4 scenes remain historical assembly references. Do not imply a new render exists until it has been generated and inspected.

The package script reads the current submission writeup and supplier remarks, verifies PDF feature coverage and ZIP contents, then refreshes checksums. No command above uploads to a supplier.

## Current presentation regeneration

```sh
/Applications/Blender.app/Contents/MacOS/Blender -b --python scripts/render_revision_Q.py
/Applications/Blender.app/Contents/MacOS/Blender -b --python scripts/render_photoreal_product.py -- --iteration Q --device METAL
/Applications/Blender.app/Contents/MacOS/Blender -b --python scripts/render_radiator_plate.py -- --revision R7 --device METAL
```

The Q renderer loads the Q-M03 faceplate explicitly. R7 produces seven views including the populated assembly, fasteners, notch and outside-corner detail. The Q inspection set has twelve views including R5 steel and C0.5 POM details; studio has four. Retain the existing tube equilibrium solution for this corner-only change.

## Composite StarTech25U scene

After the current Q/R7 source scenes and official fitting meshes exist (run `.venv/bin/python scripts/assess_manifold_side_clearance.py` for the separate40/45/50mm envelope assessment):

```sh
# Only rerun these preparation checks when tubing inputs change:
# .venv/bin/python scripts/relax_context_tubes.py
# .venv/bin/python scripts/check_pvc_equilibrium.py
/Applications/Blender.app/Contents/MacOS/Blender -b --python scripts/render_context_25u.py -- --device METAL
```

Use `--preview` for a half-resolution front overview in `tmp/`. A full run refreshes nine views (including a straight-on front tubing detail, a GPU block detail and a power-connector close-up) and `output/context-25U/25U-StarTech-context.blend`, recording source hashes in `layout.json`. `--check-only` rebuilds the native scene and verification without rendering. The preparation step requires NumPy/SciPy and writes rod solutions plus their force/stiffness checks. The Blender generator rejects stale solver inputs or changed nominal fitting routes. See [PVC physics](pvc-routing-physics.md). The generator calls `context_startech25.py`, `context_gpu5090.py`, `context_tubing.py`, `check_context_gpu.py` and `check_context_fit.py`; any failed curvature, tube-separation or mesh-intersection assertion stops the run before rendering/saving. Inspect the rear/pump detail as well as the front. Exact custom parts are retained; provisional pump/support, GPU and host envelopes remain labelled in the layout data.

## Historical reproduction

Sources and generated data for older revisions remain in their original locations. Superseded writeups and older packaging remarks are in [archive](archive/README.md); historical package scripts resolve those archived templates. See [iterations](iterations.md) for revisions and tags. Never combine an older manufacturing drawing with a newer mating part.

The composite saves a rack-centred perspective viewport with 5 mm near /10,000 mm far clipping. The previous 0.01 mm near clip provides very poor depth precision at rack viewing distances and can cause apparent z-fighting. `scripts/context_viewport.py` sets these defaults; it changes neither geometry nor render cameras. For close inspection below 5 mm, adjust the near plane temporarily rather than reverting to that extreme range for whole-rack viewing.

Operator confirmation, 15 September 2026: increasing Clip Start made the live viewport smoother. Retain the 5 mm default for the composite rack scene.

## Final three-part consistency record

Run `.venv/bin/python scripts/finalise_three_part_pack.py` to verify/recreate the delivered Q/R7 index from its retained files and review records. It is specific to that set and does not promote a new revision. The separate `release.py` workflow packages new reviewed revisions without modifying this index. Assembly instructions remain outside fabrication ZIPs.

## Reading retained structural studies

The original solver decks, results and node/load metadata are tracked together, compressed, in each study's output directory. With the FEA Python dependencies installed, `review_radiator_fea.py`, `review_radiator_expanded_load.py`, `review_radiator_R2.py` and `review_radiator_R4.py` can recalculate reports/plots directly from those files without running CalculiX again.

For a new solver run, `radiator_plate_fea.py` writes the plain `.inp` deck and compressed metadata into the corresponding study directory (R1: `output/radiator-FEA/`; expanded label: `output/radiator-expanded-load/`; R2/R4: their `analysis/` directories). Run CalculiX with that directory as the working directory and retain the resulting `.dat` there. The review script prefers these plain fresh results, then archives the decks/results as gzip. Once archived, remove the redundant plain decks/results. Midsurface geometry is an automatically disposed intermediate. Do not rerun a historical study merely to select files for manufacture.

The preserved scene-specific checks in `scripts/archive/` apply only to their named historical scenes. They are not current-design acceptance checks.

Run `.venv/bin/python scripts/check_publication.py` for read-only bundle, navigation and retained-input checks. `.venv/bin/python scripts/check_retained_inputs.py` can also check the renderer meshes, scene descriptions and all sixteen complete solver cases independently. Neither command needs Blender or CalculiX.

## Manufacturing revision terminology

The command options are `--manufacturing-revision`, `--body-manufacturing-revision` and `--faceplate-manufacturing-revision`. The four Q preparation/packaging scripts use `_manufacturing_revision.py` filenames. The canonical selection and new release manifests use schema version 2. Configuration and new verification metadata use `manufacturing_revision` (and explicit body/faceplate variants), distinct from `geometry_revision`.

Project metadata uses the current field names and source paths directly, read with Python’s standard `json` module. Source checks compare SHA-256 hashes directly with current files. There is no field translation, path aliasing or historical-hash fallback. Update payloads and consumers together when changing this format.

The 5 October 2026 metadata migration refreshed source references/checksums after terminology-only changes. It did not regenerate or alter submitted STEP/PDF/DXF/ZIP files, images or Blender scenes, and is not a new geometry or visual approval. Original generation records remain available in Git at `533c2bc`; the current metadata describes the maintained checkout.

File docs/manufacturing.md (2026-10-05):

# Current manufacturing status

As of 5 October 2026, the canonical fabricated set is **Q-M04 body, Q-M03 faceplate and R7-M01 radiator plate**. All three parts are delivered. The operator has verified the manifold body's and faceplate's dimensions, the POM M4 holes and the G1/4 ports. The radiator plate is **operator-unverified**, pending access to a spare Supernova.

## Current files

Use [the repeat-order guide](order-from-jlc.md) for another quotation, [the fabrication index](../output/submission/current-three-parts/README.md) for downloads, and [the canonical manifest](../cad/current-release.json) for machine-readable paths and hashes. Do not choose files by a historical directory's “current” label.

| Part | Manufacturing revision guide | Fabrication definition |
|---|---|---|
| Manifold POM body | [Q-M04](jlc-submission-Q-M04.md) | Chamfered slab; 28 G1/4 ports; 12 M4 threads; two long galleries |
| Manifold faceplate | [Q-M03](jlc-submission-Q-M03.md) | Raw 2 mm 304; R5 outside corners; plain holes; ±0.10 mm cut dimensions/coordinates |
| Radiator plate | [R7-M01](jlc-submission-R7-M01.md) | Raw 2 mm 304; R5 corners; plain fan/radiator holes; rounded cable notch |

The matching fabrication PDFs define finished features and inspection. STEP thread cylinders are pilots. Assembly instructions, bought-in hardware and tightening are separate: [manifold assembly](assembly-Q.md), [radiator assembly](radiator-rack-plate.md).

## Physical verification and supplier findings

The first article was made by **JLCCNC**. Smooth QD3 engagement, accepted POM corner detail and a faceplate mounting without perceptible flex are operator observations. Covered POM holding marks were accepted. Slight sharpness on the steel remains an open finish-quality finding specific to that batch. See [the JLCCNC first-article report](jlc-first-article.md).

Dimensional/fit acceptance does not imply recorded leak testing or qualification of pressure, transport loading or long-term creep. Those results have not been reported. The radiator's fit against the actual radiator and fans is still unverified. Separate side-elbow/rack-hardware clearance remains an actual-hardware concern in [the context study](context-25U.md).

## Evidence and history

- [Current design recap](three-part-recap.md): dimensions, material and interfaces.
- [Supplier requirement review](jlc-final-review.md): the reviewed process requirements and first-article checks.
- [Q-M04 machining route](Q-M04-machining-route.md): three-axis feasibility with deep-drilling capability; not JLC's actual CAM.
- [Latest order and delivery chronology](jlc-order-2026-09-16.md): approval, prices, manufacture, delivery and operator reports.
- [Original order](jlc-quotation-2026-09-15.md) and [faceplate concession](jlc-feedback-2026-09-16.md#operator-acceptance): superseded order, retained unchanged files and order-specific feedback.
- [Earlier status narrative](archive/manufacturing-status-through-2026-10-05.md): historical inspections and manufacturing revision changes.

The original order was cleared by the operator. The current parts came from the subsequent order. Neither this status record nor the repeat-order guide authorises payment or submission by an automated agent.

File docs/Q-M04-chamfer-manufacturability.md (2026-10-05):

# Q-M04 perimeter chamfers: JLC manufacturability

Checked 16 September 2026, following the operator's question during preparation of Q-M04.

The nominal C0.5 ×45° perimeter chamfers are conventional external CNC features. JLC's CNC chamfer guide describes 45° as a standard tool angle, 0.2–0.5 mm as a usual edge-safety range, and ±0.1 mm as typical for cosmetic chamfers. This supports quoting the current C0.50 ±0.10 ×45° ±1° specification; it does not establish part-specific acceptance or guarantee the angular tolerance. The previous ±0.1 mm laser/deburring concession concerned the steel faceplate, not this CNC POM part.

The CAD includes twelve edge chamfer faces and eight small triangular corner flats. The flats remove the original three-edge vertices and are accessible convex exterior surfaces. Engineering assessment: they can be cut with suitable tool access/finishing paths, but matching a compound-angle corner flat can require a separate finishing pass; it should not be represented as an automatic result of every ordinary 45° chamfer toolpath. JLC must review the actual model and drawing. No 5-axis requirement or particular machining sequence is imposed.

The current drawing retains explicit edge size/angle and identifies all eight triangular corner flats in STEP. It does not add separate micron-scale point-location or flatness tolerances to those tiny faces. If JLC requests a simpler cosmetic treatment, a wider chamfer tolerance or controlled corner blending could be evaluated separately; neither has been substituted for the accepted geometry in this revision.

The CNC design guideline states that unspecified tolerances are normally ±0.1 mm or greater and that other limits should be supplied in a 2D drawing. A catalogue statement is not approval of the complete tolerance stack. Q-M04 was subsequently submitted for file review on16September2026; the operator’s 17 September screenshot subsequently shows Q-M04 Approved, with no review comments shown. See the [approval record](jlc-order-2026-09-16.md#supplier-approval--17-september-2026). Retain original Q-M01 fabrication archives as history.

Sources (primary supplier guidance):

- [JLC chamfer machining guide](https://jlccnc.com/blog/chamfer-cnc-machining-guide), published 24 January 2026, updated 31 July 2026.
- [JLC CNC design guideline](https://jlccnc.com/help/article/cnc-machining-design-guideline), updated 20 August 2025; Tolerances and 2D Drawings sections.
- [JLC ISO 2768 overview](https://jlccnc.com/help/article/iso-2768-tolerance-standards-for-cnc-machining), updated 14 June 2025. Its embedded numerical tables were not retrievable in this check; no numerical capability claim is inferred from those unseen tables.

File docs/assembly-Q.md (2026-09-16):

# Q manifold assembly - first article

Current reference assembly uses the chamfered Q-M04 POM body and Q-M03 faceplate with R5 outside corners. Fixings, port positions and assembly procedure are retained.

**Assembly document, not a supplier manufacturing drawing.** Applies to RM10-Q-M04-BODY and RM10-Q-M03-FACEPLATE. Fabrication and JLC requirements are in [the manufacturing guide](jlc-submission-Q-M04.md). Do not place this guide in the supplier fabrication ZIPs.

## Hardware and starting condition

- Twelve **M4 ×10 ISO7380-1 A2 stainless hex-socket button screws**, 2.5 mm key, nominal Ø7.6 ×2.2 head envelope. Plain bearing heads; no countersunk screws. No washers in the reference assembly.
- Body: M4×0.7-6H,10 mm full thread after0.55 entry,13 mm full-diameter pilot plus point. Plate2 mm. Nominal screw insertion8 mm;5 mm spare to the cylindrical pilot bottom. Confirm actual screw length and tip form.
- First assembly **dry, without Loctite, other threadlocker or added lubricant**. Adhesive options remain unselected; do not use generic Loctite243 on POM by default.
- Bought-in G1/4 fittings/plugs seal with their own compatible face O-rings. No threadlocker or thread seal tape is specified on the BSPP fitting threads. The separate fitting manufacturer's assembly instructions govern those interfaces.

The reference assembly STEP and individual M4×10 screw are under `output/assembly/Q/`. Product/studio images show the same head envelope; hidden screw shanks are omitted in Blender. The former Westfield WF2237 ×16 reference establishes head appearance only; **it is not the screw length to order for this assembly**. Select an actual compliant ×10 product.

## Sequence

1. Inspect the body for loose swarf, clean passages, intact lands and sound threads. Inspect the flat plate, burr removal and window alignment. Obtain the actual-grade record.
2. Rest the plate on the body with bosses freely entering all twenty windows. Do not pull a misaligned or distorted plate into place using screws.
3. Start all twelve screws by hand before seating any. Tighten progressively in a crossing pattern from the middle towards the ends, with the body supported.
4. For the first controlled dry trial, use **0.10 Nm as an initial test setting only** with a suitable low-range calibrated driver. Record seating and retention; this is not a validated production torque. Do not apply a generic steel M4 setting or treat “finger tight” as a measurement. Do not force a screw if it binds before the head seats.
5. Confirm plate seating and absence of free movement. Check the defined handling loads with support before installing the manifold above equipment. Establish the tested torque/retention window on matching-stock coupons and the first article; see [the calculation and test plan](Q-torque-and-creep.md).
6. Install the selected G1/4 fittings/face-sealing plugs according to their own instructions. Every unused port must be sealed or fitted with a suitable self-closing coupling. There are20 front,4 side and4 rear ports. Verify both gallery assignments; no internal grouping exists.
7. Install with rack-specific screws/cage nuts at suitable available slots and check actual side-elbow/hose clearance. The six optional positions per side are choices, not a requirement to fill all of them. Complete leak/flow and warm-retention checks before operational use.

Expected duty is inhibited computer coolant, approximately50°C maximum liquid temperature assumption. There is no tested pressure/temperature/load/creep rating. The operator's two-year EK experience supports proportionate warm-retention checks; small preload relaxation and failure to retain the manifold are different outcomes. Do not retighten during a relaxation test and hide the measured change.

The manufacturing supplier is not asked to assemble these parts, apply adhesive or set a torque. The current R6 radiator assembly order remains fans onto plate → plate onto radiator → assembly onto rack, documented separately in [the radiator assembly guide](radiator-rack-plate.md).

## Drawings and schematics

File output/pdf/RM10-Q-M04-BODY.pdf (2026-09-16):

# RM10-Q-M04-BODY

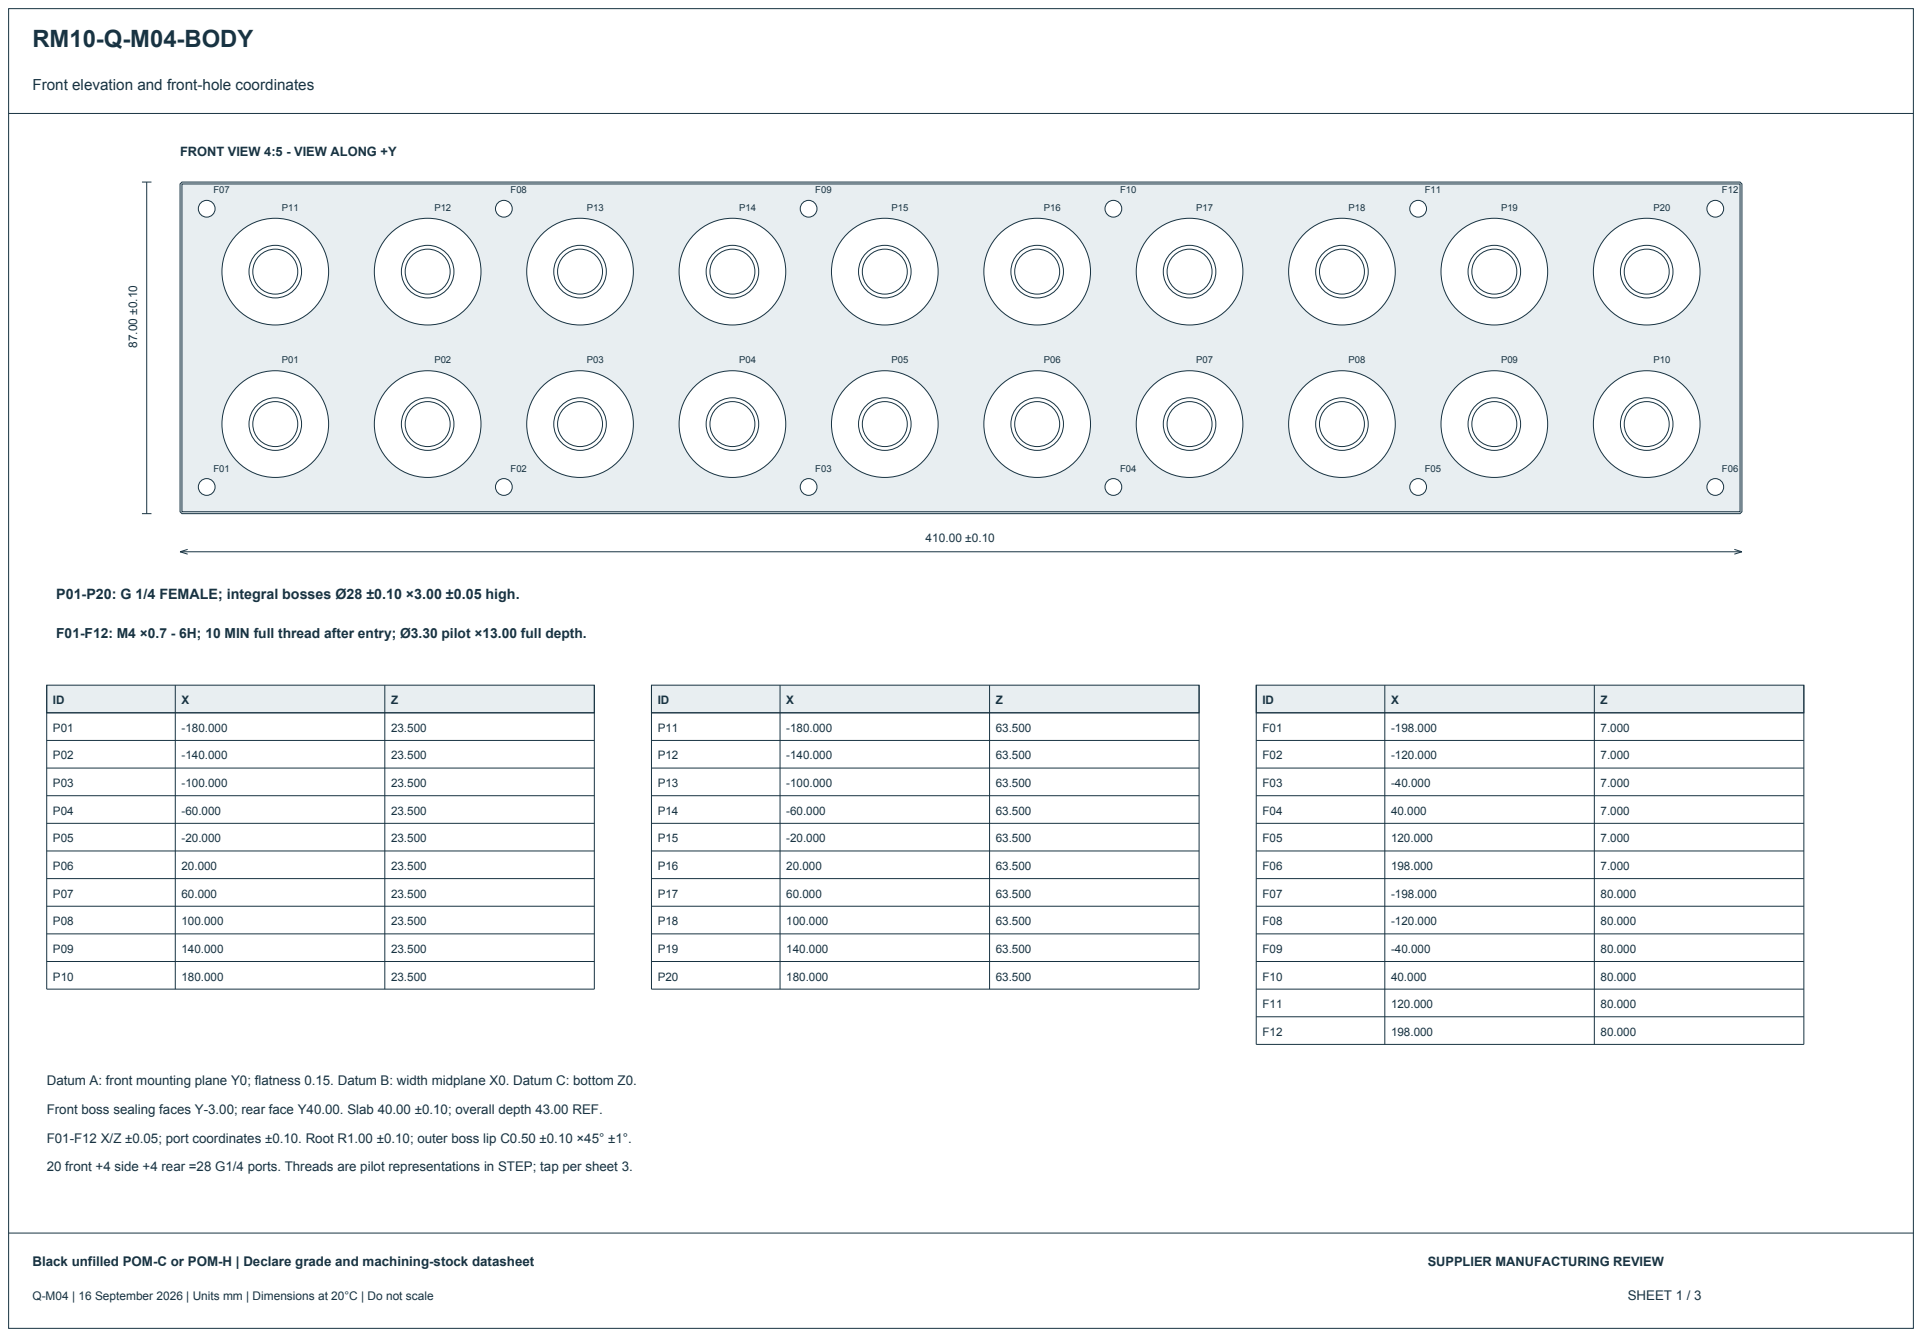
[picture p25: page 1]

Front elevation and front-hole coordinates

FRONT VIEW 4:5 - VIEW ALONG +Y

P01-P20: G 1/4 FEMALE; integral bosses Ø28 ±0.10 ×3.00 ±0.05 high.

F01-F12: M4 ×0.7 - 6H; 10 MIN full thread after entry; Ø3.30 pilot ×13.00 full depth.

Datum A: front mounting plane Y0; flatness 0.15. Datum B: width midplane X0. Datum C: bottom Z0.

Front boss sealing faces Y-3.00; rear face Y40.00. Slab 40.00 ±0.10; overall depth 43.00 REF.

F01-F12 X/Z ±0.05; port coordinates ±0.10. Root R1.00 ±0.10; outer boss lip C0.50 ±0.10 ×45° ±1°.

20 front +4 side +4 rear =28 G1/4 ports. Threads are pilot representations in STEP; tap per sheet 3.

Black unfilled POM-C or POM-H | Declare grade and machining-stock datasheet

Q-M04 | 16 September 2026 | Units mm | Dimensions at 20°C | Do not scale

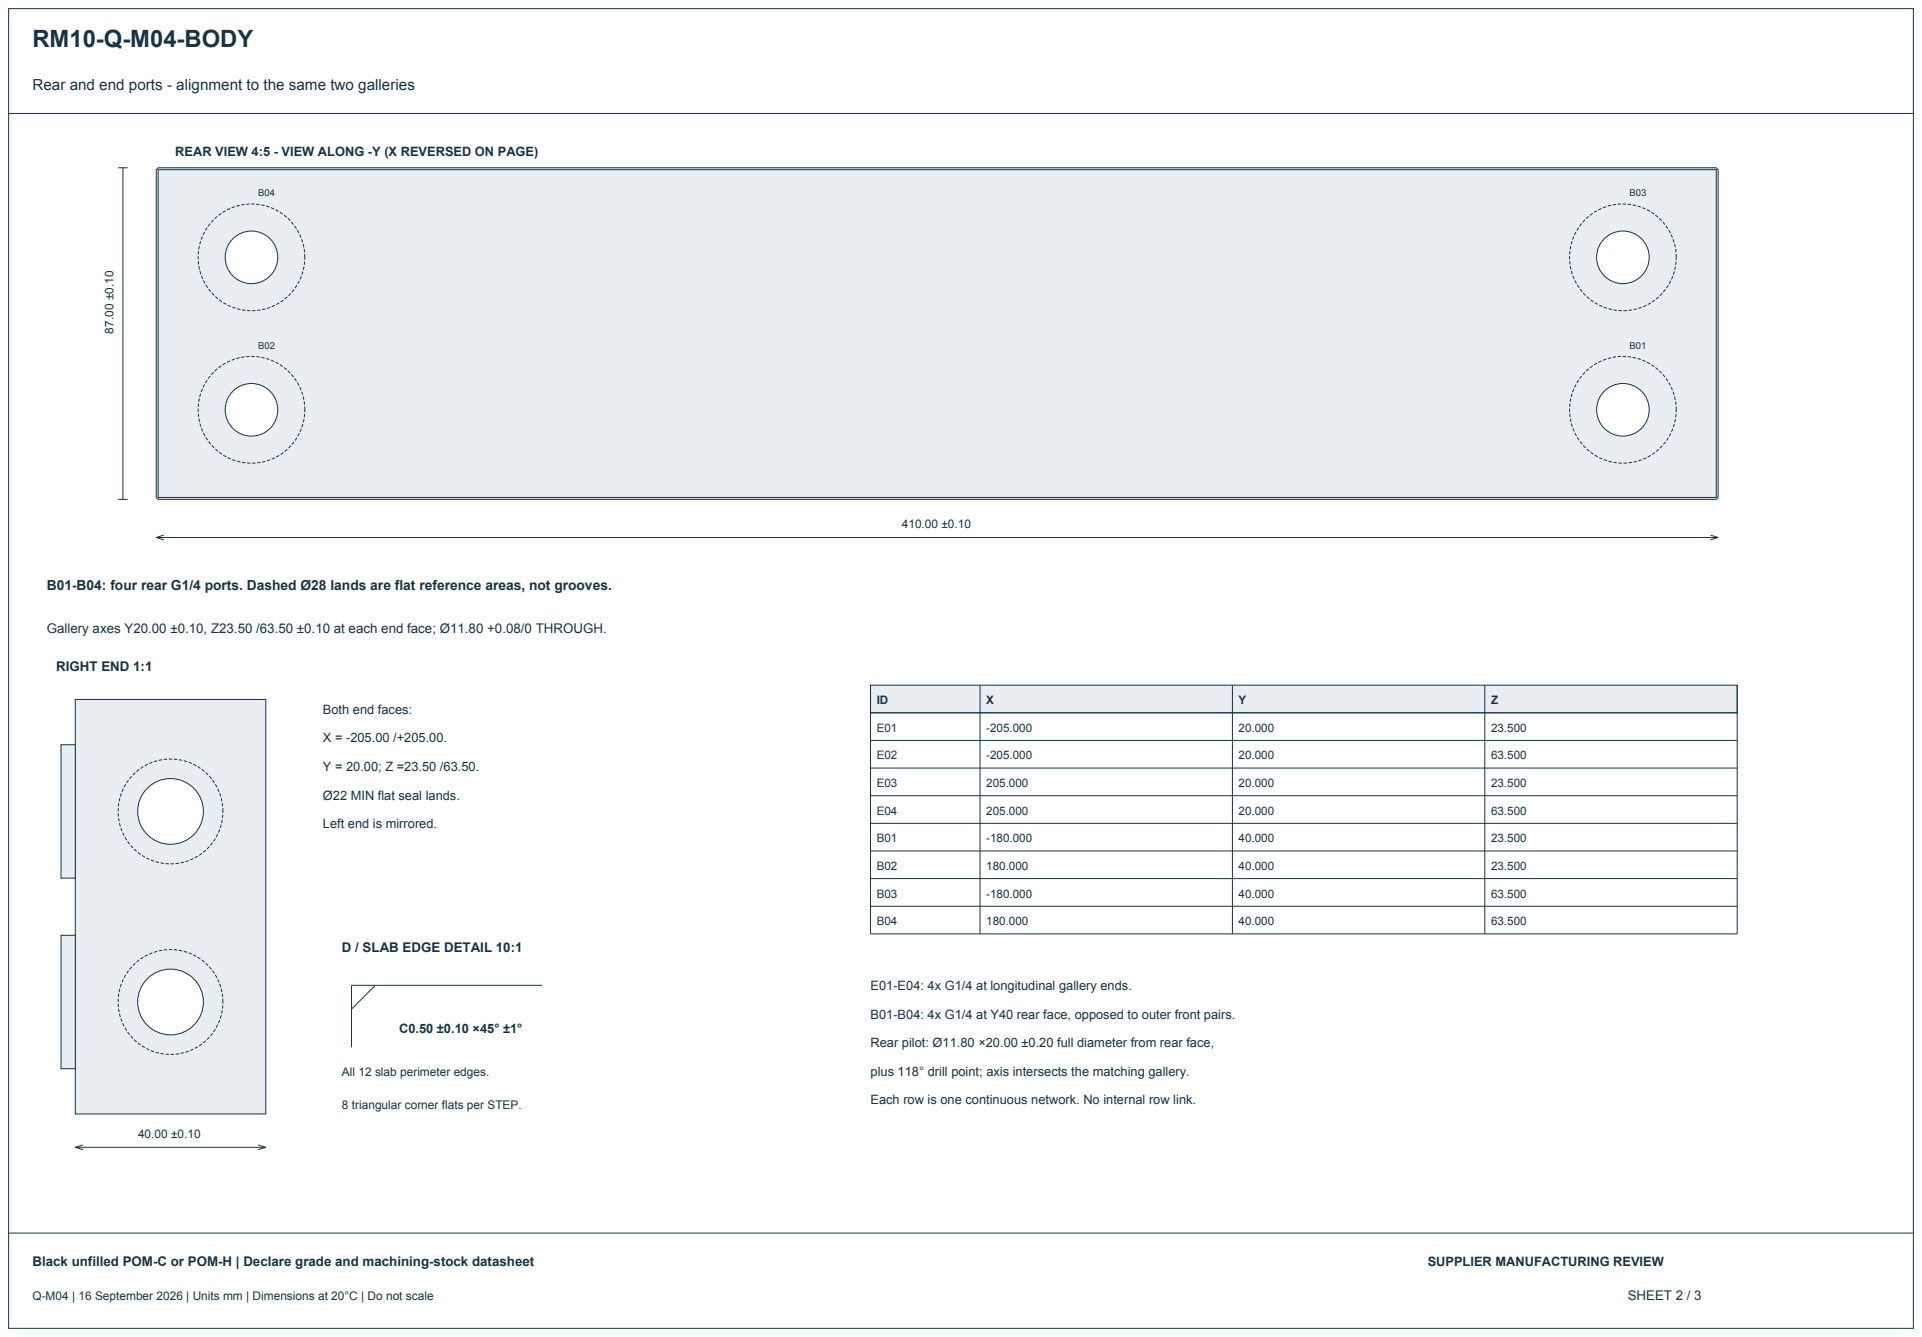
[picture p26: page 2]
RIGHT END 1:1

Rear and end ports - alignment to the same two galleries

REAR VIEW 4:5 - VIEW ALONG -Y (X REVERSED ON PAGE)

B01-B04: four rear G1/4 ports. Dashed Ø28 lands are flat reference areas, not grooves.

Gallery axes Y20.00 ±0.10, Z23.50 /63.50 ±0.10 at each end face; Ø11.80 +0.08/0 THROUGH.

Both end faces:

Ø22 MIN flat seal lands.

Left end is mirrored.

D / SLAB EDGE DETAIL 10:1

E01-E04: 4x G1/4 at longitudinal gallery ends.

B01-B04: 4x G1/4 at Y40 rear face, opposed to outer front pairs.

Rear pilot: Ø11.80 ×20.00 ±0.20 full diameter from rear face,

All 12 slab perimeter edges.

plus 118° drill point; axis intersects the matching gallery.

Each row is one continuous network. No internal row link.

8 triangular corner flats per STEP.

Port/retention sections and manufacturing requirements

A-A / THROUGH ALIGNED FRONT AND REAR PORT (2:1)

40.00 slab

Boss Y-3 | Rear Y40

Gallery axis Y20

ALL 28 PORTS: G 1/4, DIN EN ISO 228-1, parallel BSPP.

19 TPI / pitch 1.33684 REF; 55° thread form; right hand.

8 MIN full-form thread AFTER entry. Gauge to ISO 228-2.

Entry Ø13.80 ±0.10 ×90° ±1° included (45° per side);

1.00 depth REF to Ø11.80 pilot. No NPT/R/Rp substitute.

Front pilot: 23.00 ±0.20 full diameter from boss sealing face.

Rear pilot: 20.00 ±0.20 full diameter from rear sealing face.

Front/rear drill point 118° ±2° (tip inside gallery).

Thread + run-out maximum from seal face: front/end 16.00;

rear 12.00. Supplier to select tap/thread-milling process.

Section shows open passage; aligned front/rear points overlap.

Other front ports terminate in their gallery with the drill point.

M4 RETENTION / F01-F12

12x M4 ×0.7 - 6H; 10 MIN full thread after entry.

Ø3.30 ±0.05 pilot ×13.00 ±0.10 full diameter from A.

118° ±2° point; 13.99 total drilled depth REF.

Entry Ø4.40 ±0.10 ×90° ±1° included; depth 0.55 REF.

10.55 total minimum thread reach from A REF.

2.45 unthreaded full-diameter tap allowance REF.

Gauge to ISO 1502; no inserts.

Blind pilot depth excludes its conical drill point.

All twelve F holes are blind and isolated from fluid bores.

Supplier must confirm tapping/run-out before machining.

FUNCTIONAL SURFACES / FINISH

All seal lands: Ra ≤1.6 µm; local flatness ≤0.05.

Front annulus Ø13.8 to Ø27 REF; rear Ø28 flat land;

each side port Ø22 MIN flat land. No radial scratches.

Seal-face perpendicularity to thread axis ≤0.05 across Ø22.

Exterior POM Ra ≤3.2 µm; unthreaded bores Ra ≤6.3 µm.

12 slab perimeter edges: C0.50 ±0.10 ×45° ±1°; see STEP.

Other external edges: break 0.20 max; protect seal lands.

NO INTERNAL BORE / CROSS-HOLE DEBURR OPERATION.

Clean/flush loose chips; deliver dry, clean and unmarked.

No polishing, coating, impregnation or adhesive repairs.

Two Ø11.80 +0.08/0 galleries THROUGH 410 mm. Opposed drilling permitted: 207 mm reach per end /4 mm overlap REF.

Gallery centreline deviation ≤0.30 from nominal; meeting step ≤0.30; no blind web or wall breakthrough.

General DIN ISO 2768-1 class m; coordinate tolerances ±0.10 unless stated. Dimensions after stock stabilisation at 20°C.

Use sound black unfilled POM-C or POM-H stock; declare grade and supply datasheet before manufacture.

Confirm long-bore tooling, thread process and functional finishes. Report proposed deviations before manufacture.

Inspect finished threads, bore continuity, all datum dimensions, surface finishes and specified flatness.

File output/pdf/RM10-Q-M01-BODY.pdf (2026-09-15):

# RM10-Q-M01-BODY

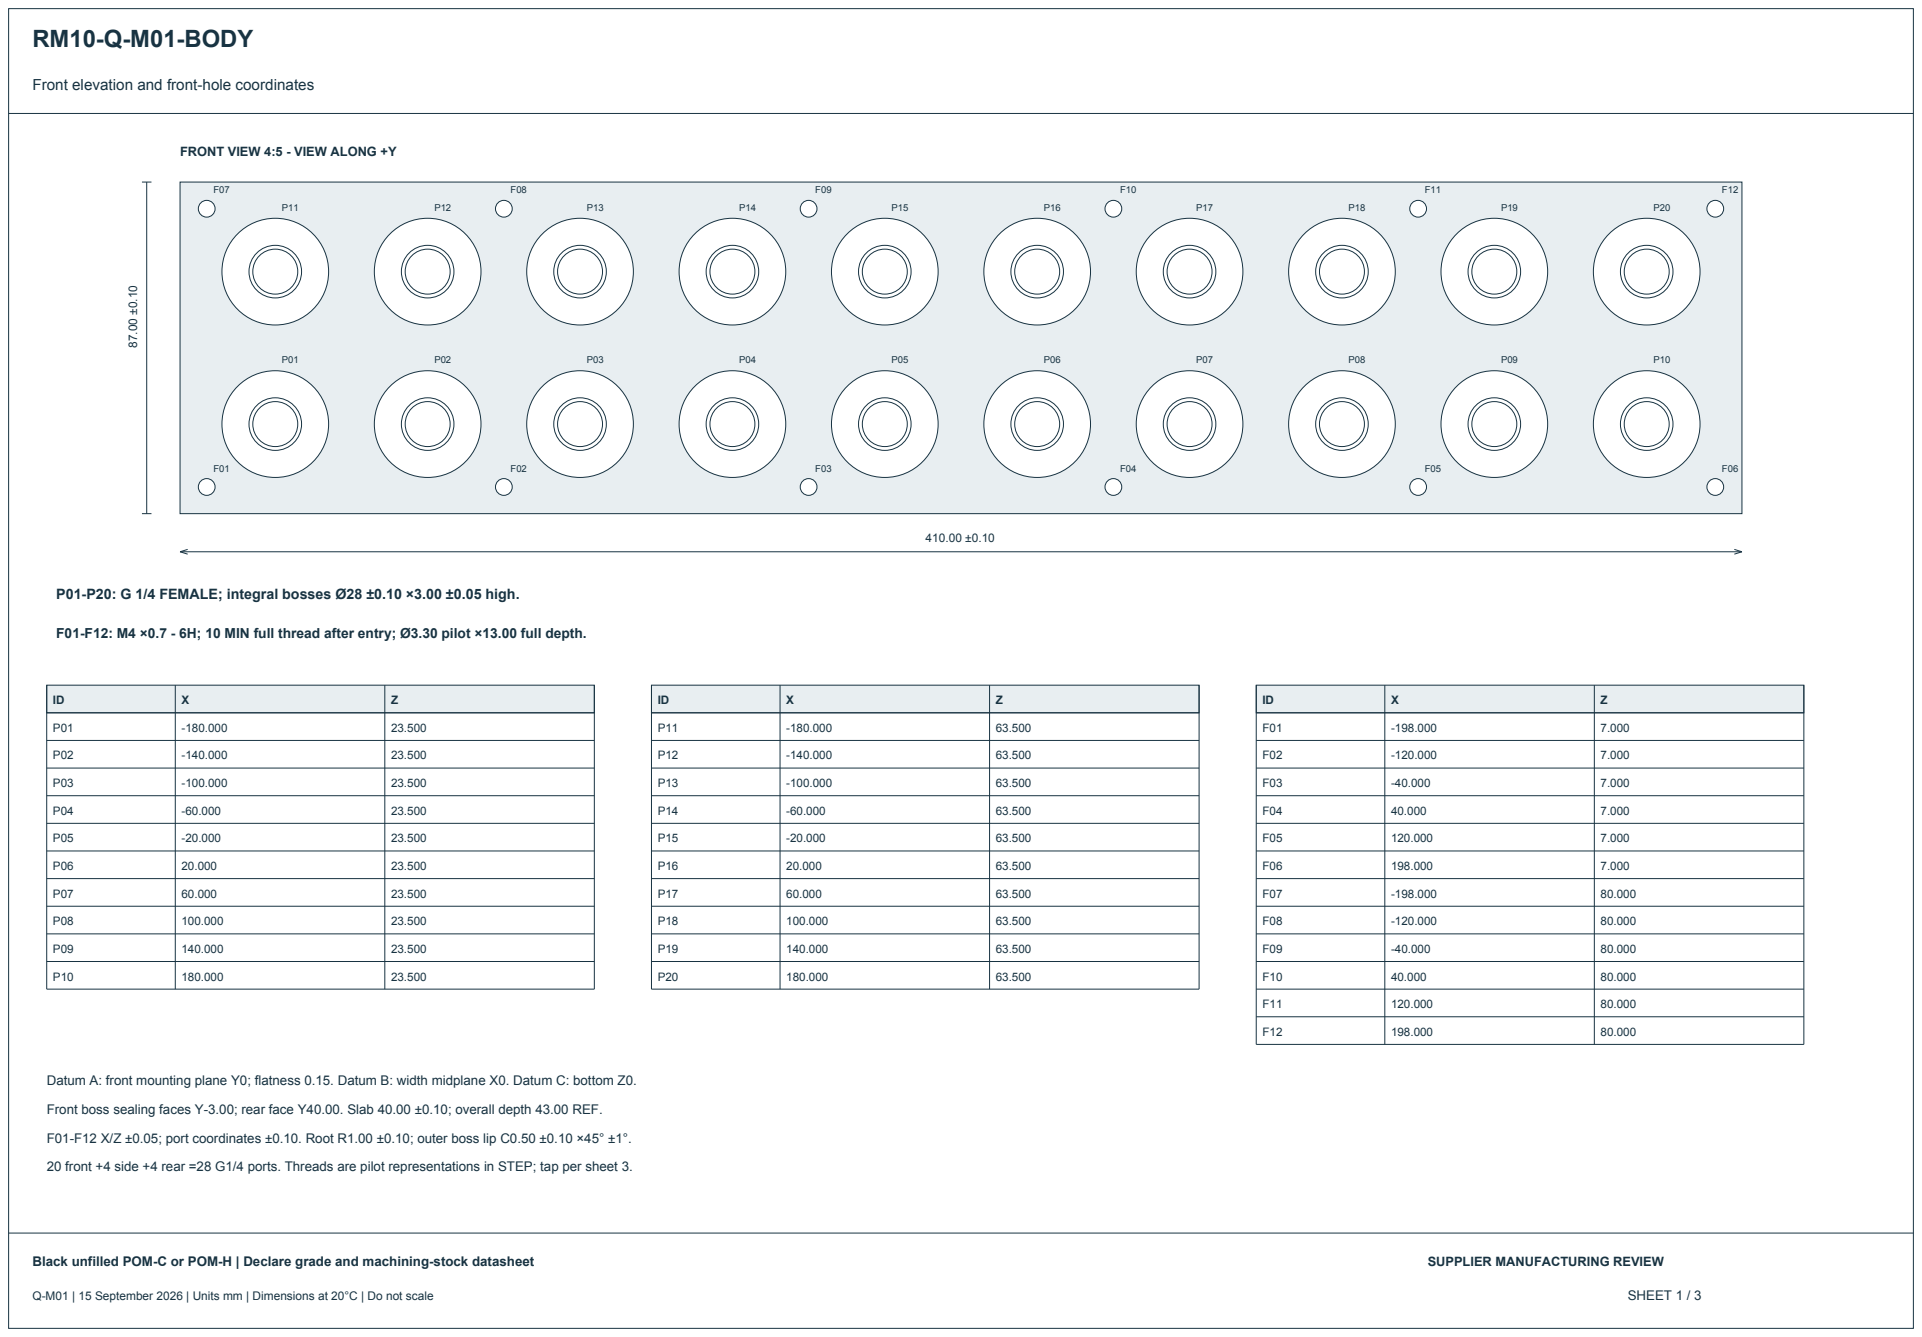
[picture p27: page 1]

Front elevation and front-hole coordinates

FRONT VIEW 4:5 - VIEW ALONG +Y

P01-P20: G 1/4 FEMALE; integral bosses Ø28 ±0.10 ×3.00 ±0.05 high.

F01-F12: M4 ×0.7 - 6H; 10 MIN full thread after entry; Ø3.30 pilot ×13.00 full depth.

Datum A: front mounting plane Y0; flatness 0.15. Datum B: width midplane X0. Datum C: bottom Z0.

Front boss sealing faces Y-3.00; rear face Y40.00. Slab 40.00 ±0.10; overall depth 43.00 REF.

F01-F12 X/Z ±0.05; port coordinates ±0.10. Root R1.00 ±0.10; outer boss lip C0.50 ±0.10 ×45° ±1°.

20 front +4 side +4 rear =28 G1/4 ports. Threads are pilot representations in STEP; tap per sheet 3.

Black unfilled POM-C or POM-H | Declare grade and machining-stock datasheet

Q-M01 | 15 September 2026 | Units mm | Dimensions at 20°C | Do not scale

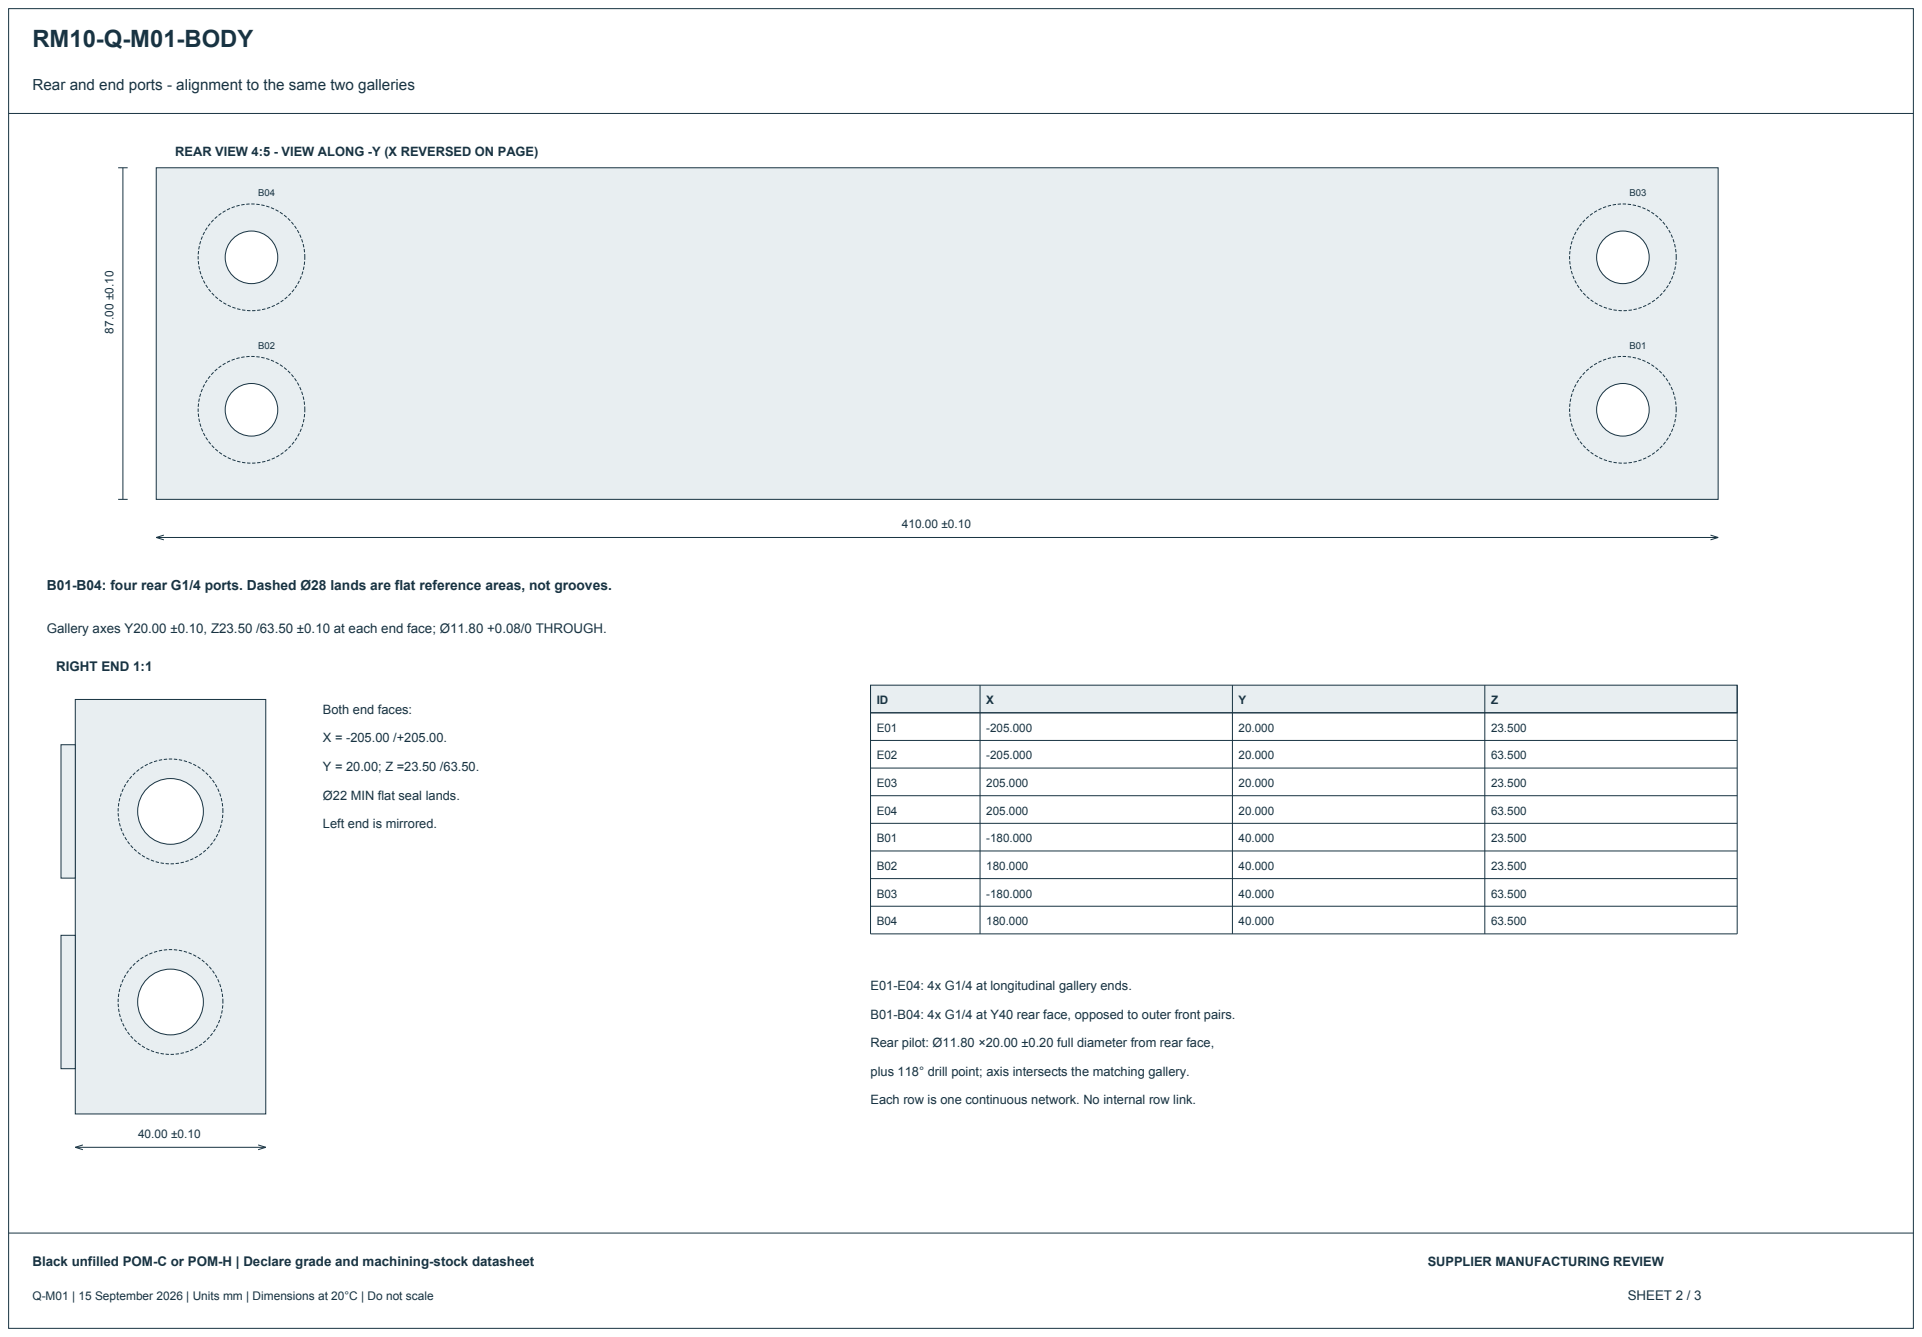
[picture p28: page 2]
RIGHT END 1:1

Rear and end ports - alignment to the same two galleries

REAR VIEW 4:5 - VIEW ALONG -Y (X REVERSED ON PAGE)

B01-B04: four rear G1/4 ports. Dashed Ø28 lands are flat reference areas, not grooves.

Gallery axes Y20.00 ±0.10, Z23.50 /63.50 ±0.10 at each end face; Ø11.80 +0.08/0 THROUGH.

Both end faces:

Ø22 MIN flat seal lands.

Left end is mirrored.

E01-E04: 4x G1/4 at longitudinal gallery ends.

B01-B04: 4x G1/4 at Y40 rear face, opposed to outer front pairs.

Rear pilot: Ø11.80 ×20.00 ±0.20 full diameter from rear face,

plus 118° drill point; axis intersects the matching gallery.

Each row is one continuous network. No internal row link.

Port/retention sections and manufacturing requirements

A-A / THROUGH ALIGNED FRONT AND REAR PORT (2:1)

40.00 slab

Boss Y-3 | Rear Y40

Gallery axis Y20

ALL 28 PORTS: G 1/4, DIN EN ISO 228-1, parallel BSPP.

19 TPI / pitch 1.33684 REF; 55° thread form; right hand.

8 MIN full-form thread AFTER entry. Gauge to ISO 228-2.

Entry Ø13.80 ±0.10 ×90° ±1° included (45° per side);

1.00 depth REF to Ø11.80 pilot. No NPT/R/Rp substitute.

Front pilot: 23.00 ±0.20 full diameter from boss sealing face.

Rear pilot: 20.00 ±0.20 full diameter from rear sealing face.

Front/rear drill point 118° ±2° (tip inside gallery).

Thread + run-out maximum from seal face: front/end 16.00;

rear 12.00. Supplier to select tap/thread-milling process.

Section shows open passage; aligned front/rear points overlap.

Other front ports terminate in their gallery with the drill point.

M4 RETENTION / F01-F12

12x M4 ×0.7 - 6H; 10 MIN full thread after entry.

Ø3.30 ±0.05 pilot ×13.00 ±0.10 full diameter from A.

118° ±2° point; 13.99 total drilled depth REF.

Entry Ø4.40 ±0.10 ×90° ±1° included; depth 0.55 REF.

10.55 total minimum thread reach from A REF.

2.45 unthreaded full-diameter tap allowance REF.

Gauge to ISO 1502; no inserts.

Blind pilot depth excludes its conical drill point.

All twelve F holes are blind and isolated from fluid bores.

Supplier must confirm tapping/run-out before machining.

FUNCTIONAL SURFACES / FINISH

All seal lands: Ra ≤1.6 µm; local flatness ≤0.05.

Front annulus Ø13.8 to Ø27 REF; rear Ø28 flat land;

each side port Ø22 MIN flat land. No radial scratches.

Seal-face perpendicularity to thread axis ≤0.05 across Ø22.

Exterior POM Ra ≤3.2 µm; unthreaded bores Ra ≤6.3 µm.

External edges: break 0.20 max unless otherwise specified.

Protect sealing lands; no general rounding of seal faces.

NO INTERNAL BORE / CROSS-HOLE DEBURR OPERATION.

Clean/flush loose chips; deliver dry, clean and unmarked.

No polishing, coating, impregnation or adhesive repairs.

Two Ø11.80 +0.08/0 galleries THROUGH 410 mm. Opposed drilling permitted: 207 mm reach per end /4 mm overlap REF.

Gallery centreline deviation ≤0.30 from nominal; meeting step ≤0.30; no blind web or wall breakthrough.

General DIN ISO 2768-1 class m; coordinate tolerances ±0.10 unless stated. Dimensions after stock stabilisation at 20°C.

Use sound black unfilled POM-C or POM-H stock; declare grade and supply datasheet before manufacture.

Confirm long-bore tooling, thread process and functional finishes. Report proposed deviations before manufacture.

Inspect finished threads, bore continuity, all datum dimensions, surface finishes and specified flatness.

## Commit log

2026-09-14 Create initial 2U parallel coolant manifold design
    [body.step, bracket_left.step, bracket_right.step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]
2026-09-14 Replace bent rack ears with a flat mounting faceplate
    [body.step, bracket_left.step, bracket_right.step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]
2026-09-14 Add a single backing plate mounting alternative
    [backplate-flat.dxf, backplate.step, body.step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]
2026-09-14 Raise integral POM port bosses above the faceplate
    [backplate.step, body.step, faceplate-flat.dxf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]
2026-09-14 Standardise faceplate mounts on M4 DIN 7991 screws
    [backplate.step, body.step, faceplate-flat.dxf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]
2026-09-14 Evaluate drilled galleries against rear-milled pockets
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2026-09-14 Quantify pressure scenarios for D5 pumps in series
2026-09-14 Resize rear glands for stock 3.53 mm EPDM seals
    [backplate-flat.dxf, backplate.step, body.step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]
2026-09-14 Adopt Polymax 3 mm rings and face-seal groove dimensions
    [backplate-flat.dxf, backplate.step, body.step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]
2026-09-14 Select front rack mounting and draft both M4 steel plates
    [faceplate-flat.dxf, manifold-assembly.step, rear-cover-flat.dxf]
2026-09-14 Render unmarked assembled manifold from eight angles
    [assembled-unmarked.blend]
2026-09-14 Add separate long-bore manifold iteration with plugged ends
    [assembled-unmarked.blend, body.step, faceplate-flat.dxf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]
2026-09-14 Add narrow and full-width long-bore manifold variants
    [assembled-unmarked.blend, body-50-percent-transparent.blend, body.step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]
2026-09-14 Render Revision I installed in a 42U open-frame rack
    [revision-I-in-42U-rack.blend]
2026-09-14 Visualise ten front pairs at 40 mm spacing in Revision K
    [assembled-unmarked.blend, body-50-percent-transparent.blend, body.step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]
2026-09-14 Assess rack-slot edge margins and washer clearance
2026-09-14 Compare six rack fixings per side with the middle-hole layout
2026-09-14 Add six available rack-fixing positions per side in Revision L
    [assembled-unmarked.blend, body-50-percent-transparent.blend, body.step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]
2026-09-14 Move outer POM fixings inward for a balanced front layout
    [assembled-unmarked.blend, body-50-percent-transparent.blend, body.step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]
2026-09-14 Render bare and connected Revision M assemblies with studio materials
    [01-bare-ports.blend, 02-qd3-translucent-tubes.blend]
2026-09-14 Preserve the 35 mm centred-gallery assessment and clearance findings
    [assembled-unmarked.blend, body-50-percent-transparent.blend, body.step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]
2026-09-14 Restore 40 mm body depth with centred galleries
    [assembled-unmarked.blend, body-50-percent-transparent.blend, body.step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]
2026-09-14 Prepare Revision O manufacturing drawings and supplier packages
    [RM10-O-M01-BODY.step, RM10-O-M01-FACEPLATE.dxf, RM10-O-M01-FACEPLATE.step]
2026-09-14 Shorten manifold bosses to project one millimetre above the faceplate
    [RM10-O-M02-BODY.step, RM10-O-M02-FACEPLATE.dxf, RM10-O-M02-FACEPLATE.step]
2026-09-14 Finalise O-M02 JLC handover and refresh boss-depth renders
    [01-bare-ports.blend, 02-qd3-translucent-tubes.blend, assembled-unmarked.blend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]
2026-09-15 Visualise O-M02 in a 24U open GPU workstation
    [24U-context.blend]
2026-09-15 Show dual MCIO 8i cables for the host uplink
    [24U-context.blend]
2026-09-15 Correct GPU power connections in the rack context
    [24U-context.blend]
2026-09-15 Allocate a 10U front radiator bay below the server
    [24U-context.blend]
2026-09-15 Include MO-RA pumping and reservoir in the cooling assembly
    [24U-context.blend]
2026-09-15 Correct MO-RA tank mounting from manufacturer references
    [24U-context.blend]
2026-09-15 Adopt a replacement fan plate for radiator rack mounting
2026-09-15 Design a 3 mm stainless rack plate for the SuperNova radiator
    [alphacool-14351-manufacturer.stl, rack-plate-R1.dxf, rack-plate-R1.step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]
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2026-09-15 Assess expanded radiator payload on the 2 mm rack plate
2026-09-15 Create revision P with plain M4 holes and button-head screws
    [01-bare-ports.blend, 02-qd3-translucent-tubes.blend, REFERENCE-M4x16-ISO7380.step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]
2026-09-15 Create a 10U radiator bracket with forty rack fixing positions
    [rack-plate-R2.dxf, rack-plate-R2.step, rack-plate-R2.stl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]
2026-09-15 Add tapped and nut-mounted radiator fan plate alternatives
    [NF-A20_Public-CAD.stp, fan-00.stl, fan-01.stl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]
2026-09-15 Assess X-Splitter compatibility with the radiator fan layout
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2026-09-15 Record the rationale for plain fan mounting holes
2026-09-15 Prepare R4 radiator plate production pack for JLC
    [SN1260-R4-M01-PLATE.dxf, SN1260-R4-M01-PLATE.step]
2026-09-15 Add rounded cable notch to radiator plate and production pack
    [SN1260-R5-M01-PLATE.dxf, SN1260-R5-M01-PLATE.step, rack-plate-R5.dxf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]
2026-09-15 Reduce radiator cable notch to 10 by 2 mm
    [SN1260-R6-M01-PLATE.dxf, SN1260-R6-M01-PLATE.step, rack-plate-R6.dxf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]
2026-09-15 Record R6 approval and recap the three current parts
2026-09-15 Refresh Revision P studio views with official Koolance fittings
    [assembled-unmarked.blend, body-50-percent-transparent.blend, qd3-ft10x13-0.stl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]
2026-09-15 Consolidate current project guidance and refresh the P R6 rack scene
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2026-09-15 Replace the generic rack with StarTech 25U and reroute PVC tubes
2026-09-15 Record acceptance of front tubing length and clearance
2026-09-15 Refine RTX 5090 FE assemblies and power connectors in the rack scene
2026-09-15 Add a four-port rear connection candidate for the manifold
    [assembled-unmarked.blend, body-50-percent-transparent.blend, body.step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]
2026-09-15 Finalise Q and R6 fabrication packs and separate assembly guidance
    [REFERENCE-M4x10-ISO7380.step, REFERENCE-assembled-with-screws.step, RM10-Q-M01-BODY.step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]
2026-09-15 Specify matching raw stainless finishes for both plates
2026-09-16 Assess unchanged Q faceplate against JLC laser capability
2026-09-16 Issue revised steel submission packs with 0.10 mm tolerances
    [RM10-Q-M02-FACEPLATE.dxf, RM10-Q-M02-FACEPLATE.step, SN1260-R6-M03-PLATE.dxf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]
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2026-09-16 Round both steel plates to R5 and refresh production files and renders
    [REFERENCE-assembled-with-screws.step, RM10-Q-M03-FACEPLATE.dxf, RM10-Q-M03-FACEPLATE.step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]
2026-09-16 Chamfer the POM perimeter and define eight corner flats
    [REFERENCE-assembled-with-screws.step, RM10-Q-M04-BODY.step, assembled-unmarked.blend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]
2026-09-17 Record JLC approval of all three current parts
2026-09-22 Record completed steel parts and staged POM production
2026-10-05 Track retained build inputs and remove disposable scratch files
    [backplate.stl, body-section.stl, body.stl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]
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
